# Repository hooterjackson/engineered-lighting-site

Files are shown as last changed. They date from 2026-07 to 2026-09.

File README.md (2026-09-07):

# Engineered Lighting · Engineering Notebook

The prototype series for the Engineered Lighting robotic spotlight — research,
bench builds, perception stack, and software — published as a book-style site.

**Live site:** <https://hooterjackson.github.io/engineered-lighting-site/>
(moving to <https://engineering.engineered.lighting> once DNS cuts over)

## Working on the site

```bash
pip install -r requirements-site.txt
mkdocs serve
```

Every push to `main` builds with `--strict` and deploys to GitHub Pages via
[`.github/workflows/publish.yml`](.github/workflows/publish.yml).

Adding a chapter: drop `09-whatever.md` (numeric prefix, H1 title, optional
`title:` front matter for the sidebar) into `docs/` — the nav picks it up
automatically; no config edits needed. A chapter that belongs in a titled
sidebar group is listed explicitly in `docs/.pages` above its `...` catch-all;
anything unlisted lands after the last group.

Chapter `- [ ]` checklists are interactive on the site (state in the
reader's browser, keyed by page slug + item position) — reordering or
inserting checklist items in a doc shifts readers' saved checkmarks.

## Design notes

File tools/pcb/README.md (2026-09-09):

# PCB chapter generator

This standard-library tool derives Docs 9 and 10 from deliberately cut hardware
snapshots. It never reads routing experiments or edits the source snapshots.
The asset roots `light-v0.1/` and `flex-v0.2/` are stable URL namespaces, **not**
revision claims. JSON, native filenames and download manifests identify revisions.

## Current inputs (8 September 2026)

- Main: `handoff/claude-pcb-learning-cbb8d9fc` in the separate hardware repository.
  LIGHT v0.2, PCB `cbb8d9fc`, 262 features, 241 fitted parts, 71 BOM rows,
  20 schematic sheets.
- Flex: `deliverables/FLEX-mixed-2026-09-08-review` in that repository.
  Upper v0.3 `0af25f8f`; unchanged lower v0.2 `21db9dba` and gimbal v0.2
  `7136c5c3`. There are 292 pads/contacts across the three designs.

Use full hashes from the snapshot verification records, not these short labels.
`build` verifies every MANIFEST.json entry before consuming either snapshot.

## Source contracts

The main handoff contains `viewer-data/board.json`, `bom.json`, `pad-enums.json`
and 17 layer SVGs; `schematic-view/index.json` and sheet SVGs; `downloads/`;
`hardware-current/` native project, BOM, placement and reports;
`fabrication-reference/`; and `public-history/` with portable evidence records.
`engineering-history/` is private input, not a blanket publication source.

The hardware-side `export_viewer_data.py` and `package_handoff.py` in the handoff
are adapted versions of the original exporters. The current packaging adapters
are `scripts/package_learning_refresh.py` and `scripts/finish_learning_snapshots.py`
in the hardware repository. Read them before cutting a later revision; they are
revision-specific, not a promise that arbitrary designs can be substituted.
The current native back-face placement convention differs from the old exporter;
rotation and coordinate checks must remain enabled.

The flex review contains shared verification/electrical/mechanical summaries,
engineering notes and reference templates, plus a directory for each design.
Each directory supplies native project files, connection-table.csv,
design-intent.json, verification.json, ERC/DRC, native geometry, CAM layer SVGs
under view/, and fabrication files. The mixed package was cut with
`scripts/package_flex_learning_refresh.py`, adapting the original
`scripts/check_export_flex.py` workflow. Unchanged designs are copied byte-exact.
The upper native project ZIP includes its custom footprint library.

## Deliberate revision changes

1. Cut and verify the hardware snapshot first. Re-run checks against that exact
   board, or label inherited evidence historical. Never copy old pass counts.
2. Update the main full PCB/ZIP/CSV hashes, SHORT, REVISION and GENERATED in
   build_pcb_assets.py, its revision-specific filenames and teaching entries.
3. Update flex.py DESIGNS if a design directory/version changes. Flex board hashes
   come from verification.json; the directory mapping is still explicit.
4. Update exact revision/census/interface expectations in the tests from the
   independently verified source contract. Do not widen geometric tolerances.
5. Edit chapter prose only outside el-pcb generated marker pairs. Regenerate all
   fourteen blocks; never hand-edit their tables.

## Local loop

Run from this site repository. Set HANDOFF and FLEX to the two snapshot folders
in your own hardware checkout (absolute local paths are not published assets).

```powershell
python tools/pcb/build_pcb_assets.py build --handoff "$HANDOFF" --flex "$FLEX"
python tools/pcb/build_pcb_assets.py render
python tools/pcb/build_pcb_assets.py check
python -m mkdocs build --strict
python -m mkdocs build --strict
.venv/Scripts/python.exe -m pytest tests/e2e -q
```

Use an interpreter with MkDocs for the strict builds, and the site's venv for
pytest. Run `build` twice against frozen inputs and compare every generated byte.
Preview with the `els-site` configuration in `.claude/launch.json`.

## Publication and evidence rules

- Publish only explicit copies in build_pcb_assets.py / flex.py and their download
  manifests: native sources, drawings, derived data, selected evidence, BOM and
  placement files, and deterministic archives. A verified input is not permission
  to publish every file inside it.
- Never publish personal KiCad state, backup directories, fp-info-cache,
  FABRICATION-REVIEW.txt, netlist.xml, vendor identifiers, owner identity or machine
  paths. The scanner checks files and archive members; do not weaken it.
- Never put Markdown under docs/assets. Notes keep their exact bytes as `.txt`.
- `intended`, `cad-checked`, `modelled-current`, `simulated-historical` and
  `measured` describe evidence, not confidence. Neither board has measured data.
  Historical claims link to the byte-exact archived published teaching record,
  containing their bound revision hash; this is not a claim of a new solver run.
- Current full-loop LED electrothermal simulation is not available. The new
  tail/contact resistance screen is narrower. The old A3 upper template is
  explicitly historical; use the current upper 1:1 SVG instead.
- CAM SVGs use a non-native frame. Keep `_frame()` and svgprep's transform
  verification, and the browser copper-bounding-box tests. J100's insertion pads
  belong on B_Cu; all other flex markers retain the F_Cu check. Never relax the
  registration tolerance to accept a visually plausible offset.
- Preserve `docs/assets/pcb/.gitattributes` (`* -text`). After staging, check
  `git ls-files --eol docs/assets/pcb/light-v0.1/kicad/engineered-lighting-rev-a.kicad_pcb`
  reports `attr/-text`, and hash the staged/committed blob, not only the worktree.
- Work on a branch and open a PR against main. CI validates PRs; only a main push
  deploys. Review approval and merging belong to the owner.

The branded successor is cut with `scripts/package_branded_learning.py`. It preserves the original electrical-baseline hashes in evidence, exports current native layer views, and leaves all flex input bytes unchanged.

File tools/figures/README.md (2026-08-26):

# Annotated photo figures — generators

One script per `docs/assets/photo-anno-*.jpg`. Each holds a `COORDS` dict of
pad/pin positions **in original-photo pixels** — the provenance for every ring
and wire the published figure draws — and composes the figure with Pillow.

Inputs are the clean camera originals in `C:\Claude\PrototypeImages`
(IMG_2449 = ESP32-C6, IMG_2450 = Valent X tape, IMG_2452 = PCA9685,
IMG_2456 = ULN2803A); output paths point at the session scratchpad they were
authored in. To regenerate, fix both path sets at the top of the script and
run `python <name>_gen.py` — then copy the render over the published asset.

| Script | Publishes |
|---|---|
| `two-hubs_gen.py` | `photo-anno-two-hubs.jpg` |
| `zone1-chain_gen.py` | `photo-anno-zone1-chain.jpg` |
| `uln-map_gen.py` | `photo-anno-uln-map.jpg` |
| `a0-bridge_gen.py` | `photo-anno-a0-bridge.jpg` |
| `spot-driver_gen.py` | `photo-anno-spot-driver.jpg` (input IMG_2453, rotated 180°) |
| `spot-star_gen.py` | `photo-anno-spot-star.jpg` (input IMG_2507) |

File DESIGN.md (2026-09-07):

# DESIGN — engineering.engineered.lighting

Visual identity for the Engineered Lighting engineering notebook (MkDocs Material).
One idea drives everything: **a dark workshop where exactly the right things are lit.**
The interface is the room; the content is what the light falls on.

Files: `mkdocs.yml` (palette/font/logo config) · `docs/stylesheets/extra.css` (tokens
at the top, everything else consumes them) · `docs/assets/el-logo.svg` + `el-favicon.svg`
· hero markup in `docs/index.md`. No theme fork, no build-chain additions. JavaScript
is confined to `docs/js/` — checklist, lightbox, and Doc 9's PCB viewer — each scoped
to the page that needs it.

---

## 1 · Color tokens

All ratios are WCAG contrast, computed against the surfaces actually used. Everything
interactive or textual meets AA (4.5:1); most of it clears AAA.

### Ground — black ramp

| Token | Hex | Role |
|---|---|---|
| `--el-bg-0` | `#000000` | Page ground, header, drawer |
| `--el-bg-1` | `#0F0D0B` | Raised: admonitions, BoM panels, progress housing |
| `--el-bg-2` | `#17140F` | Highest: kbd, focused search |
| `--el-bg-deep` | `#0B0A08` | Code blocks: a whisper above black |

True black, per the company's darkness-first principle: light is an additive
medium and only exists because of the dark behind it. The warmth lives entirely
in what's *lit* — the ink and the amber — while surface raises keep a faint warm
cast (R > G > B) so panels read as tungsten-touched, never blue-gray slate.
Panels raise by 1–2% lightness with a hairline — no drop-shadows anywhere,
because a shadow implies a light source above the interface, and here light
comes from within.

**Do:** raise a surface with `--el-bg-1` + `--el-line`. **Don't:** `box-shadow`,
blue-tinted grays, or a lifted "app background" — the page itself stays `#000`.

### Ink — warm off-whites

| Token | Hex | Role | On bg-0 |
|---|---|---|---|
| `--el-ink` | `#F2EEE6` | Headings, primary text | 18.1:1 |
| `--el-ink-2` | `#C9C1B2` | Body secondary, nav items | 11.8:1 |
| `--el-ink-3` | `#9C937F` | Captions, table headers, meta | 6.9:1 (6.3 on bg-1) |
| `--el-ink-4` | `#6E6759` | Faint: ¶ marks, footer legal — decorative/large only | 3.8:1 |

Text is 2700 K paper-white, not `#FFFFFF` — full white is reserved for nothing, so
the brightest thing on any page is always an intentional emphasis, never a default.
Hierarchy comes from this ramp plus weight; headings are never colored.

**Do:** dim to de-emphasize. **Don't:** use `--el-ink-4` for any text that must be read
(it's below AA at body sizes — it exists for glyphs and decoration).

### Accent — the tunable-white range, nothing else

| Token | Hex | Role | Contrast |
|---|---|---|---|
| `--el-amber` | `#E2A24C` | Links, active nav, progress, checks (~1800 K) | 9.5:1 bg-0 · 8.9:1 bg-1 |
| `--el-amber-hi` | `#EFBC77` | Hover state | 12.1:1 |
| `--el-amber-soft` | `rgba(226,162,76,.14)` | Tints, checked-box fill | — |
| `--el-ice` | `#D6E5F4` | Emphasis only: focus rings, selection, `mark`, live state (~6500 K) | 16.4:1 |

The site's only two colors are the two ends of the product's tunable-white spectrum.
Amber is *interactive* — if it glows warm, you can act on it. Ice is *attention* —
focus rings, selection, highlights; it never marks a link, so the two channels stay
unambiguous. Charcoal text on an amber button: 8.5:1. No red, no green, no brand blue;
cautionary states (traps) use amber + iconography, informational states use ice.

**Do:** amber = clickable, ice = look-here. **Don't:** amber behind body text, colored
headings, any saturated hue.

### The one light surface

| Token | Hex | Role |
|---|---|---|
| `--el-paper` | `#FFFFFF` | Wiring-diagram sheets |

The wiring SVGs have hardcoded white backgrounds and color-coded wires (+12 V red,
CAN-H orange…) that must not be inverted or hue-rotated — the colors are electrical
semantics. Decision: **keep them white and frame them as lit sheets** — full-bleed
white card, hairline frame, generous padding, a faint halo, mono caption below. A
schematic pinned under a downlight is exactly this brand; a CSS-inverted schematic is
a wiring hazard. (Print drops the framing and runs them full-width.)

## 2 · Typography

One hosted family: **IBM Plex Sans, weights 400 + 600** (the company's brand face;
`font: false` in mkdocs.yml stops Roboto, extra.css imports the two weights). Code and
all "chrome" labels use the **system mono stack** (`ui-monospace, SF Mono, Menlo…`) —
zero extra font weight on a workbench phone connection.

Scale (Material's base: 1rem = 20px; body = 0.8rem = 16px):

| Style | Spec | Use |
|---|---|---|
| Display | clamp(34–47px) / 600 / −0.02em / 1.08 | Landing hero only |
| H1 | 1.7em / 600 / −0.015em / 1.15 | Page titles |
| H2 | 1.3em / 600 / −0.01em | Sections (2.4em space above) |
| H3 | 1.08em / 600 | Sub-sections |
| Body | 16px / 400 / 1.65 line-height | Prose, max-width 42em ≈ 70ch |
| Chrome | mono 10–11px / 0.12em tracking / UPPERCASE | Table headers, admonition titles, captions, meta chips, prev/next labels |

Prose is capped at ~70ch; **tables, code blocks, and diagrams deliberately escape the
measure** and run the full column — BoMs are dense and diagrams want width. The mono
uppercase "chrome" voice is how the product labels itself (telemetry style); on this
site it marks *apparatus* (labels, captions, controls) as distinct from *writing*.
Headings differ by size/weight only — never color.

**Do:** mono-uppercase for labels ≤ a few words. **Don't:** uppercase whole sentences,
a third weight, Title Case.

## 3 · Spacing, radius, borders, motion

- **Spacing:** 4px grid (`--el-sp-*`). Section headings carry 2.4em of air above —
  rhythm comes from space, not rules.
- **Radius:** `0` for every panel, table, code block, button (architectural), `999px`
  only for small floating chips (meta pills, "optional" badges, back-to-top). Nothing
  in between — no 8px "app" corners.
- **Borders:** hairlines `rgba(242,238,230,.10)` and `.20` strong. Depth = border
  + surface step, never shadow. The only glows: the hero source point and the
  faint halo behind diagram sheets.
- **Motion:** 120ms hovers, 220ms fades, `cubic-bezier(.65,0,.35,1)` — damped, no
  bounce, and `prefers-reduced-motion` collapses all of it.

## 4 · The cone-of-light motif

A single radial gradient — `radial-gradient(58% 46% at 50% 0%, warm 15% → transparent)`
— with a 3px source point at its apex. It appears on the **landing hero only** (plus a
"cooling filament" gradient for `hr` dividers). It is never placed behind body text,
never repeated per-section, never animated. One room, one downlight.

## 5 · Component decisions

- **Header:** same color as the page, hairline underline — "no chrome." Search is a
  hairline slot, not a tinted pill.
- **Sidebar:** the repeated site title is hidden on desktop (the header carries it);
  chapter numbers in the existing "3 · Title" form render with tabular numerals; the
  active page is amber @ 600. (Splitting numbers into styled boxes would need template
  or JS changes — see §7.)
- **Admonitions:** quiet panels — hairline border, `--el-bg-1` fill, mono-uppercase
  title, small tinted icon. Informational family = ice; cautionary = amber. Two custom
  types ship in CSS: `!!! trap "…"` (hazard triangle) and `!!! rules "…"`
  (8-point light burst, for the golden rules). No fat left accent bars.
- **BoM checklist:** sections are panels; per-section progress is a mono amber label
  right-aligned in the summary row; the global bar's fill runs **amber → warm white as
  it completes** (the tunable range as a progress metaphor); checkboxes are custom
  15px squares — amber check, ice focus ring, fully keyboard-operable (native inputs,
  visible `:focus-visible`). Buttons are quiet mono-uppercase hairline buttons; the
  one filled (amber) button on the site is the landing CTA.
- **Tables:** hairline horizontal rules only — no zebra, no verticals, no outer box;
  mono-uppercase headers; tabular numerals; a 3%-alpha row hover for tracking dense
  BoM rows.
- **Code:** recessed `--el-bg-deep` + hairline; restrained warm/ice syntax palette
  (strings amber-family, keywords ice-family, comments 5.1:1 — all AA).
- **Footer prev/next:** mono PREVIOUS/NEXT eyebrow + plain title; amber on hover.
- **Print = the light mode:** white ground, warm-black ink, dark-amber links (5.9:1),
  nav/header/hero hidden, diagrams full-width and unframed, page-break guards on
  tables/code/admonitions.

## 6 · Logo

A downlight in section: source point, widening beam, amber pool on the ground —
the product's whole promise in three shapes. `el-logo.svg` (transparent, for the dark
header) and `el-favicon.svg` (on a charcoal tile, bolder geometry for 16px). Both pure
SVG, no text; the wordmark stays typographic.

## 7 · Verified constraints & flagged conflicts

**Verified:** 21 token pairs contrast-checked programmatically — every text/interactive
pair ≥ AA on its real surface (amber on ground 9.5:1; table above; script in review notes). Focus visible
everywhere (2px ice ring, 2px offset). Checklist keyboard-operable. One hosted family,
two weights; no decoration images — gradients only. Mobile: drawer, 44px+ targets on
nav/summary rows, tables scroll within their panels.

**Conflicts with Material's system, and the calls made:**

1. **Light mode:** not shipped. Rationale: print styles already deliver the "paper"
   context; a second screen scheme doubles QA surface and dilutes the identity. The
   tokens are scheme-scoped, so a `paper` scheme can be added later as a second
   `palette:` entry without touching components.
2. **Custom 404** would require a template override (`overrides/404.html`) — that's a
   theme fork by this brief's rules, so it's out of scope; the motif CSS (`.el-hero`)
   is 404-ready if you later allow a one-file override.
3. **Chapter numbers as separate styled elements** in the sidebar can't be done in
   CSS alone (nav labels are plain text); done typographically instead.
4. **`trap`/`rules` callouts** are styled in CSS, but the *content* currently writes
   traps as bold "If stuck:" paragraphs — adopting them means small authoring edits
   (`!!! trap "If stuck — no reply"`). The after-preview of Doc 3 shows one converted
   as a demonstration; no chapter content was otherwise touched.
5. **Scheme base:** built on `scheme: slate` with every visible color overridden,
   rather than a named custom scheme — a custom scheme name drops Material's derived
   defaults and risks unthemed corners (search modal, tooltips). Slate-as-base keeps
   those sane if a Material update adds new surfaces.

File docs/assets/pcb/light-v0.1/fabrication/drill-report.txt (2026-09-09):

Current board cbb8d9fc060c7f2b3e6b27b096a5728e789e816102ddba393c69e91020144abb
868 drill objects: fresh Excellon is identical to the independently compared electrical baseline 80195efd4e08157d8bc64d08c70a84c45f8aff5d4f8d6fb31fbb2f623022d958. Branding changes only back silkscreen. No physical inspection.

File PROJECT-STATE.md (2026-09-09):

# PROJECT-STATE — Engineered Lighting · Robotic Spotlight

*Session-handoff file: the narrative of how this repo got here, and the site's own
build state. It replaces the chat history that produced this repo. Any Claude
(Cowork, Claude Code, claude.ai) on any machine can read it for context; update it
at the end of every working session.*

> ### What to work on next is not in this file — it is in `product-os`
>
> | Question | Authoritative source |
> |---|---|
> | What should I do next, and why? Is it blocked or gated? | **product-os** |
> | Is it actually *done*? (a SHA, a path, a dated note) | **product-os** |
> | How did this project get here, and what does the site say? | **this file** + `docs/` |
>
> Start a session from
> `https://raw.githubusercontent.com/hooterjackson/product-os/main/public/llms.txt`
> — fetchable from any tool, no clone needed. With a clone: `~/Claude/product-os`,
> then `python3 tools/rank.py`.
>
> **Cite the item ID in your first message** (`EL-004`, `SITE-002`). That one token
> is what links the conversation to the work; nothing else recovers it.
>
> This is a pointer, **not a merge** — do not sync the two by hand. When they
> disagree about *status or priority*, product-os wins. When either disagrees with
> a ruling or current bench evidence in `gimbal-bench`, the ruling wins and the
> stale side gets an item.

**Last updated:** 2026-09-07 (Doc 10: the FLEX v0.2 circuits, the pull_request CI trigger, the pinnable board tooltip) — *the last edit to **this file**, not to the repo.
`git log -1` is the repo's real state; this file lags it by design.*

## What this project is

The robotic spotlight for the Engineered Lighting fixture: a silent pan/tilt head
(smart CAN servo actuators, absolute encoders) carrying a high-CRI 3-up LED spot,
exposed to Home Assistant as ordinary entities AND autonomously aimed by a
camera-driven perception stack. Full context lives in the 10-doc series in `docs/`,
published at **https://engineering.engineered.lighting/** (this repo, MkDocs
Material, deployed via GitHub Actions).

## Current state (snapshot)

- **Site:** live — 7 chapters + Doc 3b (frame) + Doc 8 (fixture build, added
  2026-07-29) + **Doc 9 (PCB learning page, 2026-09-07 — implemented and
  validated locally on branch `doc9-understand-the-pcb`; NOT pushed, NOT
  published)** + BoM checklist + AI-workflow page. Adversarial review rounds
  applied throughout, including a sitewide coherence pass after Doc 8 landed
  (seam fixes: Doc 8 body-interface note, Doc 3 + Doc 4 graduation
  pointers → Doc 8, Home card spans Docs 1–4 · 8, totals made derivable
  at $745–1085). Design pass (DESIGN.md) done.
- **Motor swap: DONE sitewide.** Earlier revisions of this file listed two
  prompts as pending; git history shows both were executed before it was
  committed. `8fb39bf` (2026-07-21) propagated RMD-L-4005 → **RMD-L-5005**
  through everything forward-looking (Doc 3 BoM $350–405, end-to-end total
  $640–985, Doc 2's availability addendum keeps the 4005 decision record,
  wiring-SVG labels edited, checklist localStorage IDs preserved). `db41f3f`
  (2026-07-22) added Doc 3b + `docs/cad/frame.scad` (parametric scaffold +
  fit coupon). The prompt files remain in `prompts/` as executed history.
- **Motors purchased; bench is live.** Doc 3 **stage 4 passed 2026-07-31**:
  motor answering on CAN at 0x141, 0xA4 moves commanded and landed to 0.01
  degrees, and the no-homing power-cycle trick verified (the encoder reported
  80.21 deg after a power-off hand rotation). Getting there cost three
  diagnosed failures, all now written into the site: stranded wire fails in
  breadboard clips two ways (splay bare, cold-flow tinned); 12.0 V is this
  24 V-nominal motor's undervoltage-latch line, not a gentle bring-up; and
  when that latches, this unit takes its CAN interface down until a power
  cycle. Doc 4 (LED bench) and Doc 5 (camera) BoMs unordered. Valent X
  sourcing is resolved on the site - click-to-buy at BuyRite/LBC ($486
  spool), BTF FCOB listed as the budget bench substitute.
- **Hardware owned:** RTX 6000 Blackwell GPU box, Home Assistant install,
  Bambu Lab X1C printer (PETG/PETG-CF on hand assumed).

## Pending work queue (in order)

1. **Bench session, in this order** (the order is the safety property):
   flash **v2** and burn down its drill list first (SAFE replays, health
   injection drill) so a regression has one suspect; then flash **v3**;
   then `commission_verify.py` both motors; then **`commission_watchdog.py`
   BEFORE any velocity drill** - 0xB3 is the only protection that survives
   the ESP32 crashing mid-move. Then jog/vel/stop drills, one move through
   the bench-UI path (the first motion came from the USB-CAN adapter), and
   the remaining rituals: multiturn, zero, limits.
2. **Stage 5 characterization** - `tools/sweep_runner.py --live` walks the
   hold/sweep/resolution protocol with dB-meter cues.
3. **Stage 6** - motor B ALONE on the bus, re-addressed to 0x142 via
   `tools/readdress.py` (0x79 is a one-shot persistent flash write).
4. **Frame** - being designed BY HAND on this bench. Doc 3b's generated
   OpenSCAD scaffold stays published as worked reference (constraints,
   STEP-measured motor geometry, boolean test suite), not as a parts list;
   the chapter now says so at the top.
4. **Later, post-bench — fixture integration v0 (hand-soldered):** port the
   Doc 4 architecture off the breadboards onto 2–3 stacked round protoboards
   ("vegetable can" round prototyping PCB, Etsy) inside a fixture body, fed
   from an E26 socket-to-wire adapter → internal 24 V PSU (decision in the
   ledger below; re-verify against the measured worst-case current from
   Doc 3 stage 10 / Doc 4 stage 7 before buying). Build notes banked now:
   reinforce the 24 V and ground rails with solid bus wire (protoboard
   traces don't carry motor current — motor power stays point-to-point in
   18–20 AWG), keep the star-ground topology, PSU on the bottom board away
   from logic, standoffs + a vent path between boards. Component deltas vs
   bench (2026-07-29): same parts, different construction — socket every
   module on female headers (C6 devkit, PCA9685s, SN65HVD230, buck; ULNs
   already socketed), WAGOs → soldered bus + pluggable pigtails (JST-XH
   per tape zone + spot; XT30 for motor power — XH is a 3 A part, RMD
   peaks hit 5–8 A), add 100 nF decoupling at
   each module's supply pins + the bulk cap from the PSU note. ULNs stay
   for v0 (first upgrade candidate if the enclosed soak runs them hot —
   MOSFETs belong to the real PCB per Doc 4). Star heatsink was specced
   for open bench — the enclosed head needs a path to outside air or a
   verified soak. Don't solder until Doc 4 stage 7 passes (freeze the
   validated architecture); first power-up of the stack still happens on
   the current-limited bench supply before the IRM goes in. Wiring docs
   drafted 2026-07-29 (chat deliverables → docs/ + docs/assets/): a
   lane-based system map (wiring-fv0-map.svg), six step diagrams
   (wiring-fv0-step1..6: power → brain → zone 1 → scale → spot → gimbal,
   each with done-when + traps), and chapter 08-build-the-fixture.md —
   all now IN THE REPO (docs/ + docs/assets/): Home + Doc 1 doc-maps
   gained row 8, the series became
   "eight-document", totals propagated $640–985 → $745–1085 sitewide,
   bom-checklist notes Doc 8's BoM lives in-chapter for now, and
   `mkdocs build --strict` verified. Review catches baked in: XT30
   for motor power, 3× 10 kΩ PicoBuck IN pulldowns vs full-on boot
   flash, bulk cap on the motor branch (start 1000 µF), bench-feed break
   in the bus, both-AC-leads-live rule, PCAs live WITH the ULNs on B2.
   The fixture BODY is Marcelo's own design track (his call, 2026-07-29)
   — the docs treat it as a parallel project, not a gap: Doc 8's scope
   note hands that track its interface list (IRM-90-24ST mount +
   terminal-cover room away from LED heat, strain-relieved E26 cord
   entry, 3× M3 standoffs + vent path for the 72 mm stack, tape ring at
   B2 height, full pan/tilt clearance + service-loop slack,
   heatsink→outside-air path, reachable B3 USB-C window). Doc 8's BoM
   folded into the interactive checklist 2026-07-29 (12 new d8-* ids —
   saved state untouched — 31→43 items, e2e count assertions updated;
   bearing drift fixed while in there: 683 or 608 per frame.scad +
   Doc 3b, where Doc 3's BoM had said 6804). Sitewide coherence review done
   2026-07-29; totals recomputed as the straight sum of per-doc highs —
   350–405 + 170–240 + 120–320 + 105–120 = **$745–1085** — and
   propagated (Home hero + footer, Doc 1 reading paths).

## Decisions ledger (one line each — full reasoning is in the docs)

- Actuators: integrated smart CAN servos over DIY FOC (Doc 2). 4005→5005 swap
  is availability-driven; geometry logic: 5005 keeps the slim pancake profile
  (siblings 4010/4015 grow in length, the dimension the yoke cares about).
- Alternates if family sells out again: CubeMars GL40 II (direct-drive, CAN,
  DigiKey) = buy-today fallback w/ protocol port; M5Stack RollerCAN ($44) = dev
  bridge. Full sweep was done July 2026 — Damiao/Robstride/CyberGear ruled out
  (geared/oversized/EOL).
- Beam: fixed Carclo 10507 (~16°); brightness abundant at 330 mA; no zoom
  hardware (beam naturally widens with throw — see Doc 5).
- Control: brightness through HA light entity only; aiming via MQTT
  `spotlight/target` (bench) → ESPHome native-API action (production);
  Auto/Hold/Manual select gates autonomy. Doc 6 is the arbiter when docs
  disagree.
- Software: stack + repo layout + hardware-free testing per Doc 7 (ESPHome
  host-platform simulated fixture is the CI trick). Licensing gates flagged for
  product phase: ESPHome GPLv3, Ultralytics AGPL.
- Spotlight payload (2026-07-29, Marcelo's call): the Cree 3-up star mounts
  in a **DLH-3UP-EH** aluminum LED housing (Ø0.99" finned barrel, 1.26"
  long, hollow 1/2"-14 NPT rear stub = wire exit) — the housing is the
  star's heatsink AND the head's sliding balance mass. frame.scad is at
  **v3** (`b11accb`, 2026-07-29, redesigned after Marcelo's fit review of
  v2): nine flat-printed plates, zero supports, one repeated T-joint
  (printed tabs into slots + M3 bolts into side-loaded square nuts);
  motors BOLTED, never friction-fit (pan = back-cover bolt pattern under
  the base; tilt = face-mount pattern + boss-clearance window, body
  OUTSIDE the arm — the RMD's 4-pin side connector makes any collar
  impossible); 608 sits in a boss-padded full-depth pocket, M8 axle runs
  through it into a captive end-plate nut and installs LAST, so the head
  is supported on both sides and the assembly order is built into the
  geometry; head = boss/main/end plates + face-bolted **cradle_ring**
  (ID = payload_od + 0.6 ≈ 25.75 mm, pinch bolt locks the slide, ring +
  plate grip the barrel near its center); two orthogonal balance trims
  (slide the housing, then the M5 nuts in the tail slot).
  docs/cad/assembly.scad `use`s the real part modules (exploded ↔
  assembled views); Doc 3b rewritten to match ("Nine Flat Parts, One
  Coupon" — the coupon now proves BOTH motor bolt patterns). The planned
  Doc 3b assembly figure was dropped: binary/base64 can't ride the
  text-only GitHub connector (asset corrupted in transit, deleted in
  `ac67684`) — the doc points readers at assembly.scad instead. The
  motor-interface numbers (mount/back BCD 43, bolt Ø2.8, boss clear 34,
  boss len 8) are MEASURE-ME nominals awaiting the calipers step. BoM
  ripple NOT yet applied (Marcelo to call): where the housing purchase
  lands — it supersedes Doc 4's flat heatsink at the fixture stage.
  Doc 3b's BoM delta now carries the small-hardware handful (~$8: M3×10
  + square nuts, M8×35 + nut, M2.5 motor screws).
- Fixture-v0 power (2026-07-29, sized smallest-possible-in-fixture): loads
  split steady vs transient — steady worst case ~25 W as designed (~40 W
  with 2× tape); dual-axis slews add ~30–40 W briefly; balanced hold ≈ 0 W.
  Smallest class: Mean Well **IRM** encapsulated PCB-mount bricks
  (87 × 52 × 29.5 mm, potted, fanless — solders onto the bottom
  protoboard). **IRM-60-24** (2.5 A) is the floor for the as-designed
  build (worst transient ~55–65 W vs its ~69 W hiccup floor — thin but
  real; add 1000–2200 µF low-ESR bulk on the 24 V rail near the motors).
  IRM-45 rejected: dual slews cross its 115% hiccup floor → rail drops
  mid-move. **IRM-90-24** (3.75 A, ~$23) has the IDENTICAL footprint and
  covers 2× tape with margin — same volume, no-regret pick. Fit check
  (2026-07-29): the chosen protoboards are 2.84"/72 mm rounds (Etsy
  "vegetable can" 4-pack, $15, 593 plated holes, no power rails) — the
  87×52 mm IRM outspans them, so use the **IRM-90-24ST** (screw-terminal,
  109×52×33.5 mm) mounted to the fixture body below the stack; that also
  keeps the heaviest part off solder pins near a vibrating gimbal. Plan on
  ~3 of the 4 rounds (power / drivers / logic — connectors eat area fast).
  Fixture-v0 BoM drafted 2026-07-29 (chat deliverable; fold into the
  future Doc 8). Keep the BoM's
  3 A slow-blow on the 24 V side; isolate + strain-relieve the
  line-voltage corner of the stack; no TRIAC/wall dimmer on the E26
  circuit (socket's 660 W rating is a non-issue at ≤100 W input);
  wall-switch power cuts already survivable (absolute encoders, no
  homing). Scaling: +4.6 W (+0.19 A @ 24 V) per foot of Valent X. Confirm
  against the stage-10 measured worst-case current before buying.
  Beginner-review deltas (2026-07-29, round 2): board allocation REVISED —
  B1 power / B2 drivers (PCAs move in WITH the ULNs + zone plugs) /
  B3 logic (C6 + SN65, bottom of stack: USB + antenna + CAN exit) — so
  only ~a dozen wires cross boards instead of all 21 dim signals; stack
  order PSU→B1→B2→B3→gimbal; build flat, stack last, inter-board slack
  1.5×. Chapter gained: Concepts block, five protoboard-soldering rules
  (incl. never-crimp JST + XT30 recessed-live convention), per-step time
  estimates, if-stuck ladders (ULN socket swap-test), a step-7 soak agent
  prompt, and the map gained a physical side-view panel. Wire strippers +
  flush cutters added to BoM maybes.
  Adversarial-review deltas (2026-07-29): 2× tape → DC fuse steps to 4 A
  SB (~3.1 A sustained nuisance-blows a 3 A); bulk cap starts at 1000 µF
  (IRM publishes no max capacitive load — downsize if power-on hiccups);
  spot wiring is 3 independent ± pairs (6 conductors, returns never
  shared); bench-supply limit → ~3 A for full-stack tests; IRM-ST block
  is L/N/+Vo/−Vo only (no FG — Class II, verified against the datasheet);
  Board 1 is over its 72 mm area budget → split power round + a
  driver/connector deck on the third round (wiring identical).

## How to resume on any machine

1. `git clone https://github.com/hooterjackson/engineered-lighting-site.git`
   — or, on an existing clone, **`git fetch` first**. A local tracking ref that
   has not been fetched will answer "up to date" while the remote is dozens of
   commits ahead; it has already lied here by 54.
2. Open the folder in Claude Code (or point a Cowork session at it).
3. Get the queue from product-os, not from this file — fetch
   `.../product-os/main/public/llms.txt` (link at the top) or run
   `python3 tools/rank.py` in `~/Claude/product-os`. Then, first message:
   *"Working on `<ITEM-ID>`. Read PROJECT-STATE.md and the docs it references,
   summarize the state that item depends on, and let's continue."*
4. Note: Cowork **local** sessions stay on the machine they ran on — this file
   carries the narrative and product-os carries the queue and the evidence.
   Neither is chat history. Keep both updated.

### 2026-07-31 — first motor motion; frame authorship; two corrections

**Stage 4 passed.** One RMD-L-5005 on the bench, answering 0x92 and executing
0xA4 to 0.01 deg, power-cycle trick verified. Three failures diagnosed on the
way, all now in the site: stranded motor CAN wires must land in screw
terminals (they fail bare AND tinned in breadboard clips); the motor rail runs
at **24 V** because 12.0 V is this unit's undervoltage-latch line; and a
latched fault takes its CAN interface down until power cycle (power cycle is
the verified recovery, 0x76 untested). LED codes are the fastest instrument:
solid = normal, slow flash = latched Level-2 error.

**Frame: designed by hand from here.** The generated OpenSCAD in Doc 3b stays
published as *worked reference* - the STEP-measured motor geometry, the
2.5 mm tapped depth, the cantilever load argument, the boolean test suite -
but the frame going on this bench is being drawn by hand with that as
inspiration. Doc 3b and Doc 3 stage 7 both say so now.

**Correction to the 2026-07-29 entry above:** it describes the RMD's port as a
"4-pin side connector". It is a **6-pin JST ZH** (VCC, VCC, GND, GND, CANH,
CANL - power doubled up), documented in Doc 3a. The collar-impossible
conclusion still holds; only the pin count was wrong.

**Correction to the frame ledger:** entries describing frame.scad at v3 (nine
flat plates, 608 bearing in a boss-padded pocket) were true as written; the
design has since moved to v8 - four parts, no bearing, no counterweight, the
tilt axis cantilevered off the motor output. See Doc 3b.

### 2026-07-31 (later) — the bench tool becomes a commissioning console

**Direction.** The gimbal debugger is being grown into the tool that sets up
the ESP32 for the whole project: gimbal first, then the LED engine, then
pairing to Home Assistant, then firmware updates. Built after a documentation
sweep (protocol V4.2 read end to end, both vendor manuals, Docs 4/6/7/8, the
Cree and Valent X datasheets) and an adversarial review that changed the
design rather than decorating it - the velocity command was redesigned, a
torque command was cut outright, and several ordering hazards were caught.

**Four decisions, recorded in the Doc 6 addendum where they belong:**

1. The spot star (warm XP-E2 + cool XP-E2 + PC Amber) sits behind ONE
   `light.spot1`, amber folded into the warm end of the CCT dial. No amber
   entity - that would be a second photometric write path.
2. The console is a sanctioned native-API client, but never a second aim
   writer.
3. Motor comm-loss watchdog 0xB3 = 3000 ms, coupled forever to >=1 Hz status
   polling while armed. Change them together or not at all.
4. Persistent motor writes stay in ritualized one-shot tools. Never firmware,
   never a UI button.

**Commissioning values sheet** (what the bench writes into the motors):
CAN ids pan 0x141 / tilt 0x142 · 0xB3 = 3000 ms · multi-turn save ON ·
travel limits mirroring +/-170 and +/-90 (UNIT UNDOCUMENTED - the tool
discovers it by probing) · accel planners in 100..60000 dps/s, and 0 on index
0 means direct tracking, not "no limit" · PID indexes are the non-contiguous
set {01,02,04,05,07,08,09} and float-format writes need motor firmware
>= 20240528.

**Known-unknowns kept as bench experiments:** 0xB6 active-reply semantics ·
whether 0x20-03 fault push persists · whether the motor-side angle limit
gates relative moves at all · what a relative move does to an axis already
running a speed loop (firmware refuses that combination until someone runs it
on purpose).

**Motor firmware updates: there is no field path.** Both manuals were checked.
Recovery and deep configuration go through the vendor's Windows setup software
over the motor's 4-pin serial port, so a USB-TTL adapter belongs in the bench
kit. This is also why `commission_verify.py` exists: a drive that loses its
CAN interface gets recovered by a factory restore that wipes its identity and
tuning, and the JSON snapshot is what makes that survivable.

**Naming:** the artifacts keep their names - the repo is still `gimbal-bench`,
the tool still lives in `tools/bench_ui`. "Commissioning console" is what it
is becoming, not a rename.

### 2026-09-07 — Doc 9: the LIGHT v0.1 PCB, viewable and downloadable

**What landed.** A final chapter, `docs/09-understand-the-pcb.md`, built around an
interactive viewer of the real board: `docs/js/pcb-viewer.js` (board viewer, part
finder, detail panel, parts-list cross-selection, 19-sheet schematic browser, hash
routing, a read-only `window.elPcb` debug API) and `docs/stylesheets/pcb.css`
(section 17, scoped to `.el-pcb` / `.el-sch`). Both registered in `mkdocs.yml`;
that plus two lines in `docs/.pages` are the only config changes.

**The governing hardware** is `engineered-lighting-rev-a.kicad_pcb`, SHA-256
`c046202efa3896d59d12bf19f55ed48b3a6c77532aac199a3a1e9a993e449310`. The page is
generated from the handoff folder prepared on 2026-09-06 and never modifies it.

**Generator.** `tools/pcb/` (standard library only) has three modes: `build
--handoff <folder>` verifies the hash chain and derives every published asset;
`render` regenerates the page's static blocks from the published JSON; `check`
re-verifies hashes, counts, the manifest and the generated blocks **without** the
handoff, so CI and the data tests can run it. Regenerate with:

```
python tools/pcb/build_pcb_assets.py build --handoff "<handoff folder>"
python tools/pcb/build_pcb_assets.py check
```

**Published assets** live under `docs/assets/pcb/light-v0.1/` — about 27 MB: 17
layer plots, 19 schematic sheets, the loose KiCad sources, the complete project
ZIP, the parts CSV, two PDFs, two assembly drawings, the fabrication reference,
and four derived JSON files. Largest single file is the 5.6 MB `.kicad_pcb`; the
previous repo maximum was a 634 kB photograph.

**`docs/assets/pcb/.gitattributes` is load-bearing.** `core.autocrlf=true` plus
CRLF source files would rewrite line endings on commit and break every SHA-256 in
the provenance chain on a Linux CI checkout. `* -text` prevents that; verified
with `git ls-files --eol` and by re-hashing the staged blobs.

**Manufacturing scope stated on the page** (as of 7 September 2026): PCBWay has
been asked to quote five fabricated boards, two of them fully assembled with all
248 purchased parts and three supplied bare. Nothing paid or authorised; assembly
process, stencil and via treatment and factory substitutions not approved. Hand
soldering appears only as optional rework. Older "bare boards for local hand
assembly" wording in the handoff and in the CSV comments is explicitly superseded.

**What the page does not claim.** No board has been powered; no firmware has been
built or flashed. Every component claim carries an evidence class — intended,
cad-checked, modelled-current, or simulated-historical bound to the older board
hash it actually came from. `measured` is never used, and a data test fails the
build if it appears.

**Checks run.** `mkdocs build --strict` twice, clean; the CI add-a-doc rehearsal;
`pytest tests/e2e -q` → **47 passed** (10 pre-existing, 14 new data checks, 23 new
browser checks). Screenshots in `test-artifacts/screens/pcb-*.png`. Layout verified
at 390, 1280 and 1800 px with no page-level horizontal scroll.

**Two fixes worth remembering.** `tests/e2e/conftest.py` now spawns
`sys.executable` rather than a literal `python3`, so the interpreter running the
tests is the one serving the site. And Material's `.md-typeset ul:not([hidden])`
rule outranks a plain class selector, so any list the viewer hides needs either
higher specificity or the `[hidden]` guard now at the top of `pcb.css`.

**Two-interpreter workflow on this machine.** The global Python 3.12 has MkDocs
but a broken pytest; the repo `.venv` has pytest and Playwright but no MkDocs.
Build with the global interpreter, test with `.venv/Scripts/python.exe -m pytest`.

**Open, and needing the owner's call before publication:**

1. The loose `.kicad_pcb` and 19 `.kicad_sch` files are published *in addition to*
   the project ZIP, as the brief asks — about 7 MB of duplication.
2. The fabrication-reference ZIP (Gerbers, drills, IPC-D-356) is derived from the
   same source and scanned clean of quote details, but has not been owner-reviewed.
3. Repository growth of roughly 27 MB.
4. Doc 9 hides its table of contents so the board and its detail panel fit side by
   side at 1280 px, as `bom-checklist.md` already does.

**Deployment.** Approved and performed the same day: branch pushed, pull request
1 merged with a merge commit (`77cdafa`), CI green, and the chapter is live at
https://engineering.engineered.lighting/09-understand-the-pcb/. The hash chain was
re-verified against files fetched back from the published site.

### 2026-09-07 (later) — Doc 10: the FLEX v0.2 circuits, a branch gate, and a board tooltip that stays put

Three separate pieces of work, in the order they were asked for.

**A `pull_request` trigger on the publish workflow.** The pull request for Doc 9
showed no checks at all, because `.github/workflows/publish.yml` only ran on pushes
to `main`. It now also runs on `pull_request` against `main`, so a branch is
validated *before* it lands rather than after. The `deploy` job carries
`if: github.event_name != 'pull_request'`, so a pull request can build and test but
can never publish, and `concurrency` is keyed by `github.ref` so a branch's run does
not cancel `main`'s. The social-card step still fails on CI for want of `cffi`; that
is pre-existing on `main` and unrelated.

**Doc 10 — `docs/10-the-flex-circuits.md`.** Three passive flexible circuits, from
their own KiCad sources, each governed by its own hash:

| Circuit | Design | Copper | Pads | `.kicad_pcb` SHA-256 (first 8) |
|---|---|---|---|---|
| Arm ribbon | `gimbal-static-v0.2` | 1 layer | 70 | `7136c5c3` |
| Upper cylinder band | `led-upper-v0.2` | 2 layers | 120 | `a5acd2a0` |
| Lower cylinder band | `led-lower-v0.2` | 2 layers | 96 | `21db9dba` |

`tools/pcb/flex.py` (invoked as `build_pcb_assets.py --flex`) verifies each hash,
renders 16 layer plots, extracts all 286 pads from the connection tables, publishes
the native sources and builds deterministic fabrication ZIPs. 53 files, 2.5 MB.

The one genuinely hard part was registration. KiCad plots these layers in a CAM
frame, not in board millimetres, so the pad coordinates from the connection table
would have landed somewhere plausible but wrong on top of them. `_frame()` parses
the `translate(A B) scale(1 -1) translate(C D)` wrapper KiCad emits and derives
`displayed_y = native_y − (D − B)`; `svgprep.prepare()` grew `wrap_transform` and
`view_box` parameters to apply it. `test_pads_are_drawn_on_the_copper` checks the
result the only way that means anything: it measures the rendered `F_Cu` bounding
box in the browser and asserts every one of the 286 markers falls inside it, on all
three boards.

One asset needed renaming. The review folder's `ENGINEERING-NOTES.md` is
Markdown, and anything ending `.md` under `docs/` is a chapter as far as MkDocs is
concerned — it was rendered as a page and awesome-pages appended it to the nav
*after* Doc 10. It is published as `ENGINEERING-NOTES.txt` instead; the bytes and
therefore the hash `34a74c6a3252` are unchanged. `test_no_asset_is_paged_by_mkdocs`
guards the whole `docs/assets` tree against a repeat.

`docs/js/flex-viewer.js` reuses the Doc 9 viewer through `window.elPcbKit`, a small
export of `PanZoom` and the DOM helpers. Two things it needed that Doc 9 did not:
these circuits are up to sixteen times longer than they are wide, so fitting the
whole length draws an unreadable hairline — the default view fills the frame with
the circuit's *height* and the reader pans along it, with a "Whole circuit" button
for the overview. And the layer cache originally stored `true` rather than the
markup, so returning to a board you had already visited rendered nothing; it now
caches `innerHTML`.

The page states its numbers honestly: the 0.346 mm worst-case alignment hold against
a 0.30 mm requirement is a computed margin, not a passed physical test, and nothing
has been submitted, ordered or paid for.

**A tooltip you can inspect without being moved.** Clicking a component on the Doc 9
board used to jump the page straight to that part's parts-list row, which on a phone
meant you could never look at a part without losing the board. Hover and click now
both open the same summary; clicking *pins* it, with a close button, and the jump to
the parts list is a button inside the summary. Hovering elsewhere no longer disturbs
a pinned summary, `markBOM` no longer scrolls, and `jumpToRow` does the scrolling and
announces it. Four tests cover the new behaviour, including a touch-only path that
asserts the page does not scroll on tap.

**Sitewide.** `docs/.pages`, `mkdocs.yml`, both document maps, the "ten-document"
phrasing, the `10 documents` hero chip, both reading paths, Doc 9's related reading
and Doc 8's forward-looking section. Doc 10 hides its table of contents for the same
reason Doc 9 does.

**Checks.** `mkdocs build --strict` twice with no warnings; `pytest tests/e2e -q`
green including 12 new flex tests; the asset scanner clean over both asset roots.

### 2026-09-08 - Docs 9/10 refreshed from the central LED revision

**Ground truth before site edits.** The accepted hardware cut, not the autorouting
experiments, supplied main LIGHT v0.2 and upper flex v0.3. All 773 entries in the
hardware FINAL-DIGITAL-ACCEPTANCE manifest rehashed without a mismatch. Accepted
manufacturing packages already existed; the missing piece was the site's handoff
and flex-review contract, not an absence of final board files.

| Board | Published native SHA-256 | Change |
|---|---|---|
| Main LIGHT v0.2 | `9c42ff8df4a3ef58ac7f16b248242f106f784dc73b5744aa6eeb2591ec120096` | New central J2 interface and reviewed routing/assembly corrections |
| Upper flex v0.3 | `0af25f8f72fb999db1bad16a8d59541a02c4eb95f838ada6dd6abadba8fe058d` | Full insertion tail with 30 back-side contacts |
| Lower flex v0.2 | `21db9dba94c6b4fd992e7c361f79d360b84270ea8c3a89099156e5972f7d6379` | Unchanged |
| Static gimbal v0.2 | `7136c5c343da3194c0ada81330edd99336b3078152bb8f1ce47f5da158f2287d` | Unchanged |

**Snapshot contracts.** The hardware repository now has
`handoff/claude-pcb-learning-2026-09-08` (196 manifest entries) and
`deliverables/FLEX-mixed-2026-09-08-review` (192 entries). Adapted versions of the
original viewer exporter, handoff packager and flex checker preserve their folder
shapes. The site verifies every manifest entry before derivation. It remains
read-only against both snapshots. Stable asset URL roots retain their old names;
revision fields and download filenames identify the actual new boards.

**What the chapters teach now.** J2 replaces six radial sockets with one Molex
30-contact interface. Zone order is 4,5,6,1,2,3, each +,+,W,N,C: twenty-four distinct
rails, with no joining of the six fused positives. The upper tail itself is the
plug, gold on the back and support on the front, with a 0.30 +/-0.05 mm total
insertion stack. Its full 42.9 mm outline remains. The main has 264 features,
243 fitted packages, 73 BOM rows and 20 schematic sheets. Four M3 holes, USB,
remaining ports and the branding are retained. Prose covers the In2 signal
exceptions, inherited In3 slot/PWM03 return-reference risk, U5 Schmitt replacement,
910-ohm CTRL pull-downs and C504's final factory installation.

**Evidence boundaries.** Current native/parity/physical-connectivity/CAM receipts
are hash-bound to the accepted revision; the site refresh does not claim to have
rerun those main engineering analyses. The upper snapshot's native ERC/DRC, parity,
endpoint oracle and standalone CAM checks were rerun: 126 pads, 222 copper flashes,
252 tracks and 192 drills. Installed strip connectivity remains conditional on
real strip through-rails. Historical per-part calculations link to the byte-exact
archived teaching record containing their original revision hashes. The current
tail/contact resistance screen is downloadable and deliberately excludes a
full-loop thermal qualification. The 0.346 mm alignment risk against 0.30 mm
remains. The old A3 PDF is explicitly historical because its upper tail is obsolete;
the current upper 1:1 SVG and insertion drawing are supplied instead.

**Publication.** Native sources, 20-sheet schematic/PDF, current placement CSV,
BOM, fabrication reference, complete upper native project and custom footprints
are linked. No generated marker content was hand-edited. No chapter was added or
removed, so sidebar/maps/counts/reading paths require no structural changes.
The lower and gimbal asset directories are byte-identical to main's prior commit.
The quotation status distinguishes submitted requests from payment or production
release; neither these PCBs nor their flex circuits have been made or powered.

**Viewer and maintenance.** The main header now derives its short hash from the
loaded data. The upper viewer opens on the insertion tail with B_Cu visible.
Its registration test checks J100 against back copper and all other markers
against front copper, retaining the original geometric tolerance. New tests cover
the exact paired main/flex pinmap, downloadable historical evidence, the full
prose hash and visible insertion contacts. `tools/pcb/README.md` documents both
contracts, explicit publishing rules, evidence vocabulary and the regeneration loop.

**Corrections to the incoming brief.** The final hardware packages existed outside
the older site-input folders. Flex hashes are self-described, but DESIGNS still
hard-codes directory names and required a v0.3 update. The old main builder checked
three governing hashes, not every input; full snapshot manifest verification is
now explicit. The workflow runs one strict build in the PR test job; its other
strict build is in the deploy job, which is skipped for PRs. Local validation
still runs the requested two strict builds. Work is on a branch for review;
merging and production release remain the owner's decisions.

**Validation.** Two asset builds were byte-identical across 163 generated asset/page files;
`render` and `check` passed for all fourteen blocks. Two strict MkDocs builds had
zero MkDocs warnings. The full suite passed: **68 tests**. The scanner inspected
160 published files and every ZIP member. The configured `els-site` preview and
browser screenshots were reviewed. Source/prose whitespace checks passed; original
CAD/SVG whitespace is deliberately preserved under the byte-exact asset policy.
All 161 staged asset files (including .gitattributes) matched their worktree bytes;
the main board reports `attr/-text` and both changed board blobs hash to the values
above. Every previously published lower/gimbal asset matched its existing Git blob.

## 2026-09-08 — PCB material appearance and reference cleanup

Added a Board materials / Engineering colors appearance control to Doc 9.
Material mode uses black substrate, white actual silkscreen, silver-colored pads,
and family-colored bodies recovered from closed native fabrication contours.
Unresolved contours remain outlines: no invented bounding-box component bodies.
These are illustrative 2D materials, explicitly not component 3D models or an
as-built photograph. Layer inspection and front/back interaction remain available.
Duplicate fabrication reference groups are suppressed at runtime, and assembly
references are off by default; the production silk stays authoritative in the
material view. Native sources, published hashes and all generated assets remain
unchanged. The ESP32 mechanical outline was checked directly against U1 User.Eco2
(18 x 25.5 mm, with a 6 mm antenna section). This annotation is guarded by the
exact current board hash; a changed board does not inherit these coordinates.
The shield and finishes are illustrative. The transparent canvas, black mask and
metallic pad gradients were visually inspected in the local preview.

**Validation.** Generator hash/scanner checks and two strict MkDocs builds pass.
The full browser/data suite passes: **70 tests**, including reference deduplication,
material switching, native module overhang and refusal to reuse that annotation
for a different board hash. No hardware sources or manufacturing files are
changed by this presentation update.

## 2026-09-08 — Grouped arm connectors and branded board snapshot

Doc 9 now consumes the deliberately cut cbb8d9fc learning handoff. Governing main
PCB SHA256: cbb8d9fc060c7f2b3e6b27b096a5728e789e816102ddba393c69e91020144abb.
The current native project, 20 schematic sheets, BOM, placement, layer views,
assembly drawings and fabrication reference agree: 262 features, 241 fitted
parts and 71 BOM rows. J9 is the six-contact spotlight connector beside the
separate J13 tilt harness; J10/J11 are removed and J12 pan remains separate.
Teaching explains the independent LED returns and the external pan service loop.
The back artwork contains the orbit logo, wordmark, website and Kahn quotation.

The black substrate, transparent canvas, white production silk, metallic pads,
colored component bodies and engineering-color alternative are preserved. The
hash guard for the unchanged U1 mechanical depiction is bound to the new board.
This remains an illustrative 2D view, not a photograph or full component model.

Electrical baseline 80195efd retains its original evidence attribution. Current
branding DRC and native/export preservation are separate records. Historical
analogue/thermal results were not relabeled as current. Submission prose states
the latest main package is prepared but not yet submitted, the unchanged gimbal
has a PCBWay inquiry, and upper/lower flex inquiries await a custom-stack route.
No hardware has been powered or production released.

All three flex design asset directories remain byte-exact; only the shared flex
index/provenance link to the new main hash changes. Doc 10 explains the updated
main-to-arm connection without inventing a new flex revision. No chapter was
added or removed, so navigation and document counts retain their existing shape.

Validation: two deterministic asset builds, render/check and two strict MkDocs
builds passed. All 71 tests passed, including material styling, module hash guard,
front/back and flex registration, and the new six-contact pin-map regression.
Front/back screenshots were reviewed; the configured els-site preview is served
locally. Publication scanner and source-byte checks remain enabled. Work stays
on the existing material-view review branch; no deployment or merge performed.

## 2026-09-08 — Completed quotation submissions and authorized publication

Updated both hardware chapters and generated status metadata against the completed
submission receipt. The latest cbb8d9fc main and all three unchanged flex designs
now have PCBWay inquiries. The request is five main boards, two fully assembled
with 241 parts each and three bare, plus two of each flex. Supplier copper,
upper-tail construction and assembly-inspection corrections remain open; quotation
submission does not authorize payment, procurement or production. Earlier JLCPCB
main submissions are not represented as this latest revision.

Native revision hashes, evidence attribution, realistic viewer styling and all
three flex design snapshots are preserved. No chapter or navigation changes.
The owner explicitly requested publication, superseding the earlier PR-only hold.
Validation and deployment results are recorded in the associated pull request.

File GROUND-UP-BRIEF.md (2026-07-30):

# Robotic spotlight frame — ground-up redesign brief

Paste this whole file as the first message of a new session.

---

## What I want

Design the printed frame for a two-axis robotic spotlight **from scratch**, in OpenSCAD. Do not start from the existing files. Read them as evidence of what has already gone wrong, then design fresh.

Work in this order, and don't skip ahead:

1. **Establish the component data.** Sources or nothing — see "Two open unknowns" below.
2. **Adversarial review** of the current design (`docs/cad/` in the repo). The defect log below is the accumulated result of four previous rounds; treat it as a list of rules the new design must not violate.
3. **Design and build** the new files.
4. **Second adversarial pass on your own work** — render every part and the assembly, look at the images, run the interference check, re-measure mass and balance. Screenshot everything and actually inspect it.
5. Deliver files + renders, then push.

Take the time to do 4 properly. Every previous round shipped a new defect because the validation was thinner than the design work.

---

## The machine

A pan/tilt spotlight for a home lighting system. Documented as an engineering notebook at **engineering.engineered.lighting**, repo **`hooterjackson/engineered-lighting-site`**, CAD lives in `docs/cad/`.

- **Two motors**, MyActuator RMD-L-5005 (CAN variant). Pan motor hangs the whole machine from a base plate; tilt motor drives the head.
- **Payload**: a LEDdynamics DLH-3UP-EH aluminium spotlight housing — a Ø25 mm barrel — held in a printed clamp.
- **One 608ZZ bearing** on the idle side of the tilt axis.
- Printed in PETG on a Bambu Lab X1C. Zero supports is a hard requirement.
- Bench-mounted via a C-clamp on a tongue off the base plate.

Current parts: `base_plate`, `yoke` (bridge + two arms, one piece), `cradle` + `cradle_cap` (the clamp), `trunnion` (printed axle), `bearing_carrier`. Plus three test pieces: `tol_coupon`, `fit_coupon`, `bore_gauge`. **You are not obliged to keep this parts breakdown** — if a better architecture exists, argue for it. Consider seriously whether the idle side (trunnion + carrier + bearing + 6 screws) earns its place against a single-arm cantilever on the tilt motor's own output bearing.

---

## Two open unknowns — resolve these FIRST

Everything else downstream depends on them, and both previous rounds of guessing produced designs that could not be built.

### 1. The motor's output face

**Does the whole front face rotate, or only an inner disc? Is there a raised boss, and how far does it stand proud?**

This decides whether a printed plate can land flat on the face or must land on a boss and nothing else. A part that bottoms on the stationary housing clamps the motor solid.

Not published anywhere reachable. Evidence so far: the RMD-L manual's RMD-50 drawing shows **no circle between Ø25 and Ø48** on the output view, and the *same manual* explicitly dimensions bosses on the RMD-90 and RMD-120. Suggestive of a flat face; not proof.

**How to close it:** `https://www.dingsmotionusa.com/s/RMD-L-5005-S.STEP`. STEP is plain ASCII — parse `CYLINDRICAL_SURFACE` radii and their axial positions, and the sorted list of distinct radii answers boss diameter, boss height and connector protrusion in one shot. Every host serving it was blocked from the previous session's sandbox; try again, and if it's still blocked ask me to download it and hand it over.

### 2. Does `assembly.scad` render all six printed parts

On my machine it renders only some of them; on the previous session's it rendered all of them, including with a deliberately mismatched file set. Unresolved. Before designing around it, have me run this in OpenSCAD alongside the three `.scad` files and report **which parts appear and exactly what the console says**:

```scad
include <frame_params.scad>
use <frame.scad>
echo(cad_version);
translate([  0,0,0]) yoke();
translate([120,0,0]) base_plate();
translate([220,0,0]) cradle();
translate([300,0,0]) cradle_cap();
translate([360,0,0]) trunnion();
translate([420,0,0]) bearing_carrier();
```

A `WARNING: Ignoring unknown variable` line names the cause immediately.

---

## Verified component data

Everything below has a source. **Anything not on this list, treat as unknown** and either find a source or make the design tolerate both answers.

### RMD-L-5005 motor
Source: *RMD-L Series Servo Actuator User Manual Rev 1.01*, §2.1 "RMD-50 SERIES" drawing — mirrored at `github.com/tigakub/RMD-L`. Plus `dingsmotionusa.com/rmd-l-collection/l-5005-motor-characteristics`.

| | |
|---|---|
| Output flange | **4 × M3 on Ø25 bolt circle** |
| Rear mount | **4 × M2.5 on a 20 × 20 mm square** (= Ø28.28 at 45°) |
| Body | Ø49, height **23.9 mm**, mass **92 g** |
| Through-bore | **Ø8.1** ("S" variant) or Ø12.7 ("L") — two different STEP files, assume mechanically distinct |
| Torque | 0.13 N·m rated, 0.42 N·m peak, 1360 rpm, 14-bit encoder |
| Load ratings | **Not published.** No bearing-load section exists in the manual. |

Earlier versions of this design used six output holes on Ø30 and an M4 rear on Ø43. Both were invented. That error alone made every part oversized by ~11%.

### DLH-3UP-EH housing
Source: `ledsupply.com/content/pdf/DLH-3UP-EH-Assembly.pdf` Rev A, and the LEDSupply product page.

| | |
|---|---|
| Clamped diameter | Ø0.99" = **25.15 mm, ±0.38 mm** ← the drawing's own two-place-decimal tolerance |
| Overall length | 1.26" = 32 mm |
| Surface | **Not finned** — "4 small channels around the diameter of the sleeve", i.e. grooves cut in |
| Mass | **0.9 oz = 25.5 g** |
| Rear stub | 1/2"-14 NPT external, 1/8"-27 NPS internal, **1/8" (3.175 mm) wire hole** |
| Optic | Ø20 mm Carclo triple TIR, ~6 mm tall, sits inside, no holder needed for the 3-Up |
| Material | 6061-T6 |

**±0.38 mm on the clamped diameter is the single most important number for the clamp.** A 0.76 mm spread. The clamp must never bottom out — the screws set the grip, not a hard stop.

**The sleeve unscrews from the slug.** Clamping the sleeve does not restrain the slug. Not a load path in this frame, but worth a build note.

**Unverified on that drawing:** it carries dimensions `0.89`, `0.80`, `0.70` and states what none of them measure. `0.89" = 22.6 mm` has been assumed to be the sleeve length (the grip length available) — plausible, unconfirmed. The stub length is *not* `1.26 − 0.89`; the 1-Up sheet gives a different difference for the same stub.

### 608ZZ bearing
8 × 22 × 7 mm, standard. Bore and OD are toleranced to about −0.008 mm / −0.009 mm (normal class). ZZ or 2RS both fine, ABEC rating irrelevant at these speeds.

---

## Defect log — every real defect found across four rounds

Each of these shipped or nearly shipped. They are the rules.

**Fits and tolerances**
- A printed shaft drawn at 7.85 mm to enter an 8.00 mm bearing bore. External cylinders print **over** size — it would have come out ~8.0 and never gone in. Nothing in the file compensated for print error at all.
- Holes drilled horizontally treated the same as vertical ones. A horizontal hole bridges and its roof sags; it needs its own fit class.
- A block drawn exactly as wide as the slot it drops into. The block grows and the slot shrinks — 0.4 mm of interference.
- A clamp whose hard stop closed before it touched a minimum-tolerance barrel. It would have gripped air.
- A bearing pocket at nominal + 0.05, i.e. interference on a steel race.

**Geometry that did nothing, or the wrong thing**
- A wire channel cut entirely inside a bore — it removed no material.
- Two "lightening pockets" whose placement expression collapsed: a no-op on one arm, a sealed void inside the other.
- A lead-in chamfer unioned *inside* the full-diameter shaft it was meant to chamfer.
- A wire hole copied by symmetry to a side no wire passes through.
- A cable route with a 6 mm gap in it and a 3.5 mm-deep tunnel no cable could be laid into.
- Yoke arms rendered 8.7 mm clear of the bridge — not connected to the part at all.

**Interference — none of these were visible in a render**
- The clamp cap's ear standing inside the tilt motor's output boss.
- The same ear inside the motor *again* after the boss went away and the whole Ø49 body became the obstruction.
- The pan motor's side connector standing inside the hard-stop post.
- A base-plate gusset through the pan motor's body.
- A cable trough cut through the root of the hard-stop post.

**Assembly and print direction**
- Bolts with no straight driver path to them — a one-piece ring clamp where the part's own body blocked every approach.
- Fasteners trapped behind a subassembly installed earlier.
- A 30 mm blade of a hard stop printed standing up, loaded across its layers, with no buttress. Layer adhesion is the weakest direction a printed part has, and a hard stop is the one feature that gets hit.
- Clamp ears 2.6 mm thick carrying the full clamp load of an M3.
- A 32 mm circular pocket roof printed as a bridge where a hexagon with a vertex up would have been a self-supporting 60° peak.
- A shaft run at its minimum diameter along its whole length when only the last 9 mm was inside the bearing — the rest an unsupported plastic cantilever with the head hanging off it.

**Process**
- A `module` defined inside an `if` block — parser error.
- A patch that silently didn't apply because of whitespace, leaving a part rendering empty.
- STL centre-of-mass read straight out of a file exported in *print* orientation and interpreted as if it were in model coordinates. Wrong by the transform.

---

## Design rules that came out of it

- **Every number lives in one file.** `frame_params.scad` is `include`d by both the geometry and the assembly, so the assembly view cannot disagree with the parts you print.
- **Every fit is derived, never typed.** Three measured constants — vertical hole shrink, bridged hole shrink, external shaft growth — and fit functions built on them: `free_h`, `free_hx`, `tap_h`, `press_h`, `slip_s`, `loc_h`, `slot_fit`. A `tol_coupon` part measures those three on the user's own printer, and it is printed before anything else.
- **Anything that must be round prints as a vertical hole or a first-layer pocket.** Never as a bridge.
- **Every joint is a bolt you can see.** No captive nuts, nothing friction-fit. Printed-to-motor joints use the motor's own threads; printed-to-printed self-taps into pilot holes.
- **Where a part lands on a rotating boss it lands on the boss and nothing else** — if a boss exists at all. Derive the recess from the boss height so it disappears when the height is zero.
- **Assembly order is a property of the geometry, not a hope.** Every step must leave the next step's fasteners reachable by a straight driver.
- **Balance by construction, not ballast.** Offsetting the tilt axis above the payload's axis costs nothing and puts the head's measured centre of mass on the axis. It deleted a trim bolt and a washer stack.
- **Zero supports, no overhang past 60°.**
- Print orientation is declared per part inside the file — `part="yoke"` emits a slice-ready STL.

---

## Validation — do all of this, not some of it

**Render and look.** Headless: `xvfb-run -a openscad -o out.png -D 'part="x"' --imgsize=W,H --projection=p --colorscheme=Tomorrow --autocenter --viewall --camera=0,0,0,rx,ry,rz,0`. Then actually read the image. Several defects above were visible and went unnoticed because renders were generated but not inspected.

**Boolean interference check.** The single highest-value technique found. Emit `intersection() { partA_positioned(); partB_positioned(); }` to an STL and measure its volume. Zero volume or no file at all means clear; anything else is a collision. Run it for the head vs the yoke at tilt 0 and ±90°, head vs both motors, plate vs motor, carrier vs arm. **This caught three collisions that no render showed.** Note that OpenSCAD writes no file at all when the result is empty — that is the success signal.

**Mass properties.** `trimesh` on exported STLs gives volume and centre of mass. Use it to (a) find where the plastic actually is before deciding what to lighten, and (b) solve for the tilt-axis offset that nulls the head's CoM. **Export in model coordinates for this, not print orientation** — the transform will silently corrupt the answer otherwise.

**Watertightness.** Check every exported STL.

**Sanity-echo the derived chain** and read the numbers. Span, sweep vs drop, web thicknesses where two pockets cross, thread engagement depths.

---

## Repo and push protocol

If you are running with direct git access, just commit and push normally.

If the only write path is the GitHub MCP connector (`git push` fails, no credentials; direct API/curl blocked):

- `push_files` is **text only** — never send base64 or binary.
- One commit per call, full file content each time.
- **Read the final local bytes immediately before pushing.** Never reconstruct a file from memory or from an earlier read.
- Verify after every push: `git show origin/main:$f | diff - $f | wc -l` must be `0`.

Either way, the site must build clean: `python3 -m mkdocs build --strict`, and `PLAYWRIGHT_BROWSERS_PATH=/opt/pw-browsers python3 -m pytest tests/e2e -q` (9 tests).

**Current repo state:** `frame_params.scad` and `frame.scad` are v7 on main. `assembly.scad` is still v6 — it works with the v7 pair but lacks a version banner and draws M4-sized screw graphics on an M2.5 circle. There is a newer `frame_params.scad` than main delivered as a file in the previous session, carrying the housing tolerance work described above; ask me for it.

---

## Docs that need updating when the CAD settles

- `docs/03b-print-the-frame.md` — the frame chapter. Currently describes v6 numbers.
- `docs/03-build-the-gimbal.md` — row 11 of the BoM still reads "683 or 608 bearings". There is no 683 in this design; it's one 608ZZ, and it needs its own row with the rows below renumbered.
- `docs/bom-checklist.md` — already has the 608 as its own line.

---

## Deliverables

- `frame_params.scad`, `frame.scad`, `assembly.scad` — or a better file structure if you can justify one.
- STL for every part, watertight, in print orientation.
- Renders: every part individually, the full parts layout, the assembly assembled / exploded / sectioned / at tilt extremes.
- A short written adversarial review of the old design and of your own new one, with the numbers behind each claim.
- Pushed to the repo once verified.

**Tell me plainly when a number is unverified.** The whole reason this is a rebuild is that a design was shipped on invented dimensions. "Not published, here's how the design tolerates either answer" is a good outcome. A confident wrong number is not.

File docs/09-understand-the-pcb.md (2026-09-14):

---
title: 9 · Understand the PCB
description: "The integrated LIGHT v0.2 board, part by part: an interactive viewer of the real eight-layer PCB, all 262 features explained from their own nets, the 20-sheet schematic, the exact parts list and the KiCad sources."
hide:
  - toc
---

# Doc 9 · Understand the PCB — LIGHT v0.2, the Integrated Board

**Engineered Lighting prototype series · September 2026**

[Open the PCB build shopping checklist →](09a-pcb-build-bom.md){ .md-button }

Order the remaining parts for two fixtures: motors, optics, diffuser, mounting supplies and exact cable-side connectors. Check off purchases as you order; selection notes identify the items still needing a fit or specification decision.

Everything the bench proved and [Doc 8](08-build-the-fixture.md) hand-soldered has been drawn as one
circuit board: a 76.2 × 75.1 mm disc with a flat under the antenna, eight copper layers, and parts on
both faces. One ESP32-C6 module, two PWM expanders, 21 ambient channels, three constant-current
spotlight drivers, a CAN transceiver for the motors, and a protected 24 V supply feeding all of it.

This chapter is for understanding that board before it exists in your hands. Turn it over, click any
part and find out what it does *there* — not what a resistor does in general, but what this resistor
does on this net. The schematic, the parts list and the actual KiCad files are all here too.

!!! info "Where this sits after Doc 8"

    [Doc 8](08-build-the-fixture.md) is the *previous* stage: the bench architecture hand-soldered onto
    three round protoboards, with a dev-kit ESP32, PCA9685 breakouts, ULN2803 arrays and a PicoBuck
    driver, fed by an internal 24 V supply. It works, and it is how the design was learned.

    This board is the next stage, and it is not the same machine. The switching is done by 21 discrete
    MOSFETs rather than Darlington arrays; the spotlights get three independent constant-current
    drivers rather than one shared board; the power path gains an electronic breaker, a supervisor and
    a physical ARM interlock. **Doc 8's parts, wiring and ESPHome examples are not this board's
    implementation**, and the bench measurements in Docs [3](03-build-the-gimbal.md) and
    [4](04-full-fixture-bench.md) are not measurements of this PCB.

!!! warning "Status as of 8 September 2026 — designed, not built"

    This page shows the latest **grouped arm connectors and branding** revision, `cbb8d9fc`,
    submitted to PCBWay for quotation and engineering review with **241 fitted parts per assembled board**.
    The request is five fabricated main boards: **two fully assembled on both sides with sourced
    components**, and three supplied bare. Earlier main revisions were also submitted to JLCPCB.
    No payment, procurement or production release is authorized. Supplier stack, stencil, via treatment,
    final capacitor installation and substitutions remain open.

    **No LIGHT v0.2 PCB has been powered.** Current DRC and native/export preservation checks bind the
    branded board to the electrically reviewed `80195efd` baseline. That baseline has ERC, pin-parity,
    connectivity and independent CAM evidence. Those checks are not physical tests or a new simulation.

    [Doc 10](10-the-flex-circuits.md) covers the unchanged three flex circuits. The static gimbal has
    a PCBWay inquiry, as do the upper and lower LED flexes: two of each for two fixture prototypes.
    The quote-form copper and upper-tail support/finish placeholders require engineering correction;
    they do not change the specified construction. Assembly inspection settings also await correction.
    Their geometry and hashes have not been revised for this update.

## Latest changes: arm connectors and branding

The three two-pin spotlight sockets became **one six-pin J9** beside the separate **J13 tilt**
connection. Pins **1/2, 3/4 and 5/6** carry spotlight channels 1, 2 and 3. Their LED-minus wires remain
independent driver returns: sharing a connector does not make them ground. **J12 pan** remains a
separate edge connection because its cable terminates at the pan motor.

Wires link J9 and J13 to the static arm flex. The wire service loop must accommodate pan motion of
180 degrees each way; the static flex itself is not qualified as a repeatedly bending hinge.

The underside now carries the small orbit logo, **engineered lighting**, the website and the Louis
Kahn quotation. This branding changed only back silkscreen. Black substrate, white ink, metallic
pads and the overhanging ESP32 depiction remain illustrative viewer materials, not an as-built photo.

The revision sequence is `9c42ff8d` (central LED interface), `80195efd` (grouped arm connectors), then
`cbb8d9fc` (back-side branding). The upper insertion tail and lower/gimbal boards are unchanged.

??? info "Words this chapter uses — open this if any of them are new"

    | Word | What it means here |
    |---|---|
    | **Schematic** | The drawing of what connects to what. It says nothing about where parts sit. |
    | **Layout** | The drawing of where everything physically goes. This page's viewer shows the layout. |
    | **Reference designator** | A part's address on this design: `U1`, `R101`, `J14`. The letter hints at the kind of part (R resistor, C capacitor, U integrated circuit, Q transistor, D diode, L inductor, F fuse, J connector, S switch, TP test point, H mounting hole), and the number identifies the instance. It is not the part's value, and the prefix alone never explains what a part does. |
    | **Net** | One electrical connection, everything joined to it. `GND` is a net; so is `ZONE1_W`. |
    | **Trace** | The physical copper that implements part of a net. A schematic line is a *connection*, not a scale drawing of a wire — one line can become a trace that crosses three layers. |
    | **Rail** | A net that distributes power: `+3V3`, `+5V`, `V24_BUS`. |
    | **Ground** | The circuit's voltage reference and return path. It is not automatically an earth connection. |
    | **Pin vs GPIO** | A chip's physical pin number and its software name are different things. On this board, module pad 25 is the serial transmit line the firmware calls GPIO16. |
    | **Layer** | One sheet of copper inside the board. This one has eight, with insulating material between them. |
    | **Via** | A small plated hole that carries a net from one layer to another. |
    | **Pad** | Exposed copper a part's pin solders to. A pad belongs to the board, not to the part. |
    | **No-connect** | A pin deliberately left unconnected, marked so the design tools know it is intentional. This board has 29 of them. |
    | **Silkscreen** | Printed ink labels. Ink, not copper, and not a connection. |
    | **Solder mask** | The insulating coating over the copper. Its artwork describes the **openings** where copper is left exposed — so a "mask" view shows holes in the coating, not the coating. |
    | **Fab / assembly outline** | A drawing layer showing component bodies and orientation for assembly. Not electrical. |
    | **Courtyard** | The clearance a part reserves around itself so neighbours can be placed and soldered. Nothing physical. |
    | **BOM** | Bill of materials: the parts list. Distinct from *fabrication outputs* (Gerbers, drill files), which describe the bare board itself. |
    | **Bare PCB vs PCBA** | A bare PCB is the board alone. PCB assembly (PCBA) is that board with the parts fitted and soldered. They are quoted, priced and ordered separately. |
    | **ERC / DRC** | Electrical-rule and design-rule checks: automated checks that the schematic and the layout obey stated rules. They do not run the circuit. |

    One more, because it matters on this page: an animated path showing where current *would* flow is
    an explanation. It is not a live electrical measurement.

## The board { #the-board }

Start with **U1** at the top — the radio module, the part that overhangs the flat edge. Then find
**J1** on the left, where the 24 V supply lands. Hover or tap any part to see what it does; use **Flip
face** to see the underside, where the power section and the big capacitor live. The reference
labels here are the same ones used in the schematic and in the parts list.

<div id="el-pcb" class="el-pcb" data-base="../assets/pcb/light-v0.1/" data-state="nojs" data-face="F" data-preset="components" data-selected="" markdown="0">
<div class="el-pcb-fallback">
<p><strong>The interactive viewer needs JavaScript.</strong> Without it, use the <a href="#assembly-references">assembly drawings</a>, the <a href="#parts-index">parts index</a> and the <a href="#connectors">connector pinmaps</a> below, or the <a href="../assets/pcb/light-v0.1/downloads/schematic.pdf">complete schematic PDF</a>. Every part on this page is explained in the parts index whether or not the viewer runs.</p>

<noscript>Assembly drawing of the front face of the LIGHT v0.2 board, showing component outlines and reference labels</noscript>
</div>
</div>

??? info "What this view shows — and what it does not"

    The default **Components** view is an *assembly-outline* view: real positions, real body outlines
    from the board's own fabrication layer, real land shapes from its pad data, and the actual
    reference labels. It is not a photograph and not a 3D render. The project includes references to KiCad library 3D models, but no assembled model of this board has been produced or verified, and
    none is published here.

    The black ground is the **specified** solder-mask colour of a board that has not been
    manufactured. Layer colours are view colours chosen for contrast — copper is not orange, and the
    inner layers are not green and pink. The **mask** views show the *openings* where copper stays
    exposed, not the coating. **Courtyard** is placement clearance, not a physical feature.

    Some parts overhang the board edge on purpose: the radio module past the flat, the USB connector
    at the bottom and one connector on the right. They are drawn unclipped, because that is where they
    really are. Turning the board over mirrors the whole geometry once about the board's centre line,
    so what you see is the physical back face, not a mirror image of the front.

    **Inspecting a part.** Hovering one opens a short summary. Clicking or tapping it *pins* that
    summary, so it stays put and gains its own buttons: jump to the part's row in the parts list, open
    its schematic sheet, or drop to the full explanation. Nothing moves the page until you press one of
    those buttons — which is what makes this usable on a phone, where there is no hover and where the
    parts list is a long way down. The pinned summary closes with its **×**, with <kbd>Esc</kbd>, or by
    tapping bare board; the selection itself survives all three.

    **Getting around:** drag to pan, scroll or pinch to zoom, double-click to zoom in. The toolbar has
    zoom, fit and flip buttons for anyone not using a mouse. With the viewer focused, the arrow keys
    pan, <kbd>+</kbd> and <kbd>-</kbd> zoom, <kbd>0</kbd> fits the board and <kbd>f</kbd> flips it. The
    search box finds any of the 262 features by reference, name, value, part number or net — that is
    the fastest route on a phone, and the keyboard-friendly one.

    On a phone, one finger scrolls the page as usual and two fingers pan and zoom the board. If you
    would rather drag the board with one finger, press **Lock board for panning**.

## Earlier changes: the central LED interface { #revision-history }

The first published layout was LIGHT v0.1 (`c046202e`). This page now shows LIGHT
v0.2 (`cbb8d9fc`), paired with upper flex v0.3 (`0af25f8f`). Lower flex and the
static arm ribbon remain v0.2: their native board bytes did not change.

Six radial LED sockets have become **one locking Molex 2005280300 at J2**, on the
left side of the front face. J3–J7 have been removed. The upper flex's tail is the
plug itself; no twenty-four-wire solder harness is needed between it and the main
board. Thirty contacts provide twenty-four distinct connections: each zone gets
two positive contacts and its own warm, neutral and cool switched returns.
**Sharing a connector does not join the six fused positive rails.** Zone 7 still
uses J8 on the underside. Motor, spotlight, USB, ARM and expansion interfaces and
the four M3 mounting holes remain.

Routing this interface required local part moves and new signal paths on In2,
which also carries 24 V copper. The reviewed ground references remain, but they
are not uninterrupted sheets. PWM03 crosses a **1.465544 mm** interruption caused
by the inherited PCA_OE routing on In3. The adjacent/reference copper was reviewed;
edge noise and coupling still need measurements on the prototype. An autorouter's
completed connection is not proof of a good high-frequency return path.

The earlier audit corrections are included too: U5 is now **74HCS08PWJ** with
Schmitt inputs, R526–R528 are **910 Ω**, and C504 has a provisional custom land
without paste. Its one-reflow limit requires final factory installation. These
changes explain why old timing or power calculations cannot simply acquire the
new board hash. The source now has 262 features, 241 fitted packages, 71 BOM rows
and 20 schematic sheets, including the shared interface sheet.

Flip to the back to see the white orbit logo, **engineered lighting**, website and quotation.
The black-and-white finish is a fabrication request, not a photo of a built board.

## How the circuit works

Each heading below names the parts involved; select any reference to jump to it on the board. Facts
are tagged so you can tell a design intention from a CAD result from an open question.

### 24 V in, and what guards it

External 24 V arrives at **J1** — pin 1 positive, pin 2 return — and meets **F1**, a 6.3 A backup
fuse. **D500** clamps incoming spikes. **Q500** is a reverse-blocking transistor: connect the supply
backwards and nothing downstream sees it. **U12** is the real protection: an electronic breaker that
limits current, ramps its output up gently, watches for over- and undervoltage and reports what it
sees. Its behaviour is set by the resistors around it, not by software.

The mains supply is a separate unit. Mains never enters this PCB.

### The protected bus, and the branches off it

Past the breaker the rail is `V24_BUS`. **C504**, the 1000 µF can on the back, is the local energy
store that absorbs the motors' current spikes. **U501** clamps transients close to where they arrive,
and **J16** taps the protected bus for a brake that has not been designed yet.

Every branch leaves through its own fuse: **F2** and **F3** for the two motors, **F4**–**F10** for
the seven ambient zones, **F11** for the logic branch. A fuse rating protects the wiring; it is not a
statement about what the copper can carry, and it is not a current limit.

### Making 5 V and 3.3 V

**U10** converts 24 V to 5 V through **L500**; **U11** converts 5 V to 3.3 V through **L501**. Both
are switching converters, which chop their input and let an inductor average the result — far more
efficient than burning off the difference as heat. The 5 V budget is about **0.8 A in total**,
counting the 3.3 V converter's own draw and the CAN transceiver. That is not 0.8 A of spare
accessory power.

### The controller

**U1** is an ESP32-C6 module: chip, flash, crystal and printed antenna, pre-certified as a unit.
**R1** and **C1** hold it in reset while 3.3 V rises; **S1** restarts it and **S2** selects its
download mode; **J15** is the serial console. Its pad numbers are not GPIO numbers — read the map,
do not count pins.

### The 21 ambient channels

Two PWM expanders, **U2** at address 0x40 and **U3** at 0x41, generate the dimming waveforms. Each of
the 21 channels is the same four parts: a 220 Ω gate resistor, a 100 kΩ pull-down, a 2.2 kΩ pull-up
to the switched gate-bias rail, and an AO3422 MOSFET that completes the LED circuit to ground.

Two details decide whether firmware works on the first try. The expander outputs are **open-drain**:
they can only pull down, so releasing an output is what turns a channel *on*, and the optical duty is
the complement of what you write. And the second expander's outputs are **remapped by routing** —
logical channel 18 is its output 13, logical channel 20 is its output 12. Never subtract 16.

<!-- el-pcb:generated channels start -->

<div class="el-pcb-scroll">
<table class="el-pcb-table">
<thead><tr>
<th>Logical channel</th><th>Zone and colour</th><th>Expander output</th><th>Package pin</th><th>Gate resistor</th><th>Switch</th><th>Leaves at</th><th>Fused by</th>
</tr></thead>
<tbody>
<tr><td>1</td><td>Zone 1 warm</td><td>U2 output 0</td><td>6</td><td><span class="el-pcb-ref" data-pcb-ref="R101">R101</span></td><td><span class="el-pcb-ref" data-pcb-ref="Q101">Q101</span></td><td><span class="el-pcb-ref" data-pcb-ref="J2">J2</span> contact 18</td><td><span class="el-pcb-ref" data-pcb-ref="F4">F4</span></td></tr>
<tr><td>2</td><td>Zone 1 neutral</td><td>U2 output 1</td><td>7</td><td><span class="el-pcb-ref" data-pcb-ref="R102">R102</span></td><td><span class="el-pcb-ref" data-pcb-ref="Q102">Q102</span></td><td><span class="el-pcb-ref" data-pcb-ref="J2">J2</span> contact 19</td><td><span class="el-pcb-ref" data-pcb-ref="F4">F4</span></td></tr>
<tr><td>3</td><td>Zone 1 cool</td><td>U2 output 2</td><td>8</td><td><span class="el-pcb-ref" data-pcb-ref="R103">R103</span></td><td><span class="el-pcb-ref" data-pcb-ref="Q103">Q103</span></td><td><span class="el-pcb-ref" data-pcb-ref="J2">J2</span> contact 20</td><td><span class="el-pcb-ref" data-pcb-ref="F4">F4</span></td></tr>
<tr><td>4</td><td>Zone 2 warm</td><td>U2 output 3</td><td>9</td><td><span class="el-pcb-ref" data-pcb-ref="R104">R104</span></td><td><span class="el-pcb-ref" data-pcb-ref="Q104">Q104</span></td><td><span class="el-pcb-ref" data-pcb-ref="J2">J2</span> contact 23</td><td><span class="el-pcb-ref" data-pcb-ref="F5">F5</span></td></tr>
<tr><td>5</td><td>Zone 2 neutral</td><td>U2 output 4</td><td>10</td><td><span class="el-pcb-ref" data-pcb-ref="R105">R105</span></td><td><span class="el-pcb-ref" data-pcb-ref="Q105">Q105</span></td><td><span class="el-pcb-ref" data-pcb-ref="J2">J2</span> contact 24</td><td><span class="el-pcb-ref" data-pcb-ref="F5">F5</span></td></tr>
<tr><td>6</td><td>Zone 2 cool</td><td>U2 output 5</td><td>11</td><td><span class="el-pcb-ref" data-pcb-ref="R106">R106</span></td><td><span class="el-pcb-ref" data-pcb-ref="Q106">Q106</span></td><td><span class="el-pcb-ref" data-pcb-ref="J2">J2</span> contact 25</td><td><span class="el-pcb-ref" data-pcb-ref="F5">F5</span></td></tr>
<tr><td>7</td><td>Zone 3 warm</td><td>U2 output 6</td><td>12</td><td><span class="el-pcb-ref" data-pcb-ref="R107">R107</span></td><td><span class="el-pcb-ref" data-pcb-ref="Q107">Q107</span></td><td><span class="el-pcb-ref" data-pcb-ref="J2">J2</span> contact 28</td><td><span class="el-pcb-ref" data-pcb-ref="F6">F6</span></td></tr>
<tr><td>8</td><td>Zone 3 neutral</td><td>U2 output 7</td><td>13</td><td><span class="el-pcb-ref" data-pcb-ref="R108">R108</span></td><td><span class="el-pcb-ref" data-pcb-ref="Q108">Q108</span></td><td><span class="el-pcb-ref" data-pcb-ref="J2">J2</span> contact 29</td><td><span class="el-pcb-ref" data-pcb-ref="F6">F6</span></td></tr>
<tr><td>9</td><td>Zone 3 cool</td><td>U2 output 8</td><td>15</td><td><span class="el-pcb-ref" data-pcb-ref="R109">R109</span></td><td><span class="el-pcb-ref" data-pcb-ref="Q109">Q109</span></td><td><span class="el-pcb-ref" data-pcb-ref="J2">J2</span> contact 30</td><td><span class="el-pcb-ref" data-pcb-ref="F6">F6</span></td></tr>
<tr><td>10</td><td>Zone 4 warm</td><td>U2 output 9</td><td>16</td><td><span class="el-pcb-ref" data-pcb-ref="R110">R110</span></td><td><span class="el-pcb-ref" data-pcb-ref="Q110">Q110</span></td><td><span class="el-pcb-ref" data-pcb-ref="J2">J2</span> contact 3</td><td><span class="el-pcb-ref" data-pcb-ref="F7">F7</span></td></tr>
<tr><td>11</td><td>Zone 4 neutral</td><td>U2 output 10</td><td>17</td><td><span class="el-pcb-ref" data-pcb-ref="R111">R111</span></td><td><span class="el-pcb-ref" data-pcb-ref="Q111">Q111</span></td><td><span class="el-pcb-ref" data-pcb-ref="J2">J2</span> contact 4</td><td><span class="el-pcb-ref" data-pcb-ref="F7">F7</span></td></tr>
<tr><td>12</td><td>Zone 4 cool</td><td>U2 output 11</td><td>18</td><td><span class="el-pcb-ref" data-pcb-ref="R112">R112</span></td><td><span class="el-pcb-ref" data-pcb-ref="Q112">Q112</span></td><td><span class="el-pcb-ref" data-pcb-ref="J2">J2</span> contact 5</td><td><span class="el-pcb-ref" data-pcb-ref="F7">F7</span></td></tr>
<tr><td>13</td><td>Zone 5 warm</td><td>U2 output 12</td><td>19</td><td><span class="el-pcb-ref" data-pcb-ref="R113">R113</span></td><td><span class="el-pcb-ref" data-pcb-ref="Q113">Q113</span></td><td><span class="el-pcb-ref" data-pcb-ref="J2">J2</span> contact 8</td><td><span class="el-pcb-ref" data-pcb-ref="F8">F8</span></td></tr>
<tr><td>14</td><td>Zone 5 neutral</td><td>U2 output 13</td><td>20</td><td><span class="el-pcb-ref" data-pcb-ref="R114">R114</span></td><td><span class="el-pcb-ref" data-pcb-ref="Q114">Q114</span></td><td><span class="el-pcb-ref" data-pcb-ref="J2">J2</span> contact 9</td><td><span class="el-pcb-ref" data-pcb-ref="F8">F8</span></td></tr>
<tr><td>15</td><td>Zone 5 cool</td><td>U2 output 14</td><td>21</td><td><span class="el-pcb-ref" data-pcb-ref="R115">R115</span></td><td><span class="el-pcb-ref" data-pcb-ref="Q115">Q115</span></td><td><span class="el-pcb-ref" data-pcb-ref="J2">J2</span> contact 10</td><td><span class="el-pcb-ref" data-pcb-ref="F8">F8</span></td></tr>
<tr><td>16</td><td>Zone 6 warm</td><td>U3 output 0</td><td>6</td><td><span class="el-pcb-ref" data-pcb-ref="R116">R116</span></td><td><span class="el-pcb-ref" data-pcb-ref="Q116">Q116</span></td><td><span class="el-pcb-ref" data-pcb-ref="J2">J2</span> contact 13</td><td><span class="el-pcb-ref" data-pcb-ref="F9">F9</span></td></tr>
<tr><td>17</td><td>Zone 6 neutral</td><td>U3 output 1</td><td>7</td><td><span class="el-pcb-ref" data-pcb-ref="R117">R117</span></td><td><span class="el-pcb-ref" data-pcb-ref="Q117">Q117</span></td><td><span class="el-pcb-ref" data-pcb-ref="J2">J2</span> contact 14</td><td><span class="el-pcb-ref" data-pcb-ref="F9">F9</span></td></tr>
<tr><td>18</td><td>Zone 6 cool</td><td>U3 output 13 (remapped)</td><td>20</td><td><span class="el-pcb-ref" data-pcb-ref="R118">R118</span></td><td><span class="el-pcb-ref" data-pcb-ref="Q118">Q118</span></td><td><span class="el-pcb-ref" data-pcb-ref="J2">J2</span> contact 15</td><td><span class="el-pcb-ref" data-pcb-ref="F9">F9</span></td></tr>
<tr><td>19</td><td>Zone 7 warm</td><td>U3 output 3</td><td>9</td><td><span class="el-pcb-ref" data-pcb-ref="R119">R119</span></td><td><span class="el-pcb-ref" data-pcb-ref="Q119">Q119</span></td><td><span class="el-pcb-ref" data-pcb-ref="J8">J8</span> contact 2</td><td><span class="el-pcb-ref" data-pcb-ref="F10">F10</span></td></tr>
<tr><td>20</td><td>Zone 7 neutral</td><td>U3 output 12 (remapped)</td><td>19</td><td><span class="el-pcb-ref" data-pcb-ref="R120">R120</span></td><td><span class="el-pcb-ref" data-pcb-ref="Q120">Q120</span></td><td><span class="el-pcb-ref" data-pcb-ref="J8">J8</span> contact 3</td><td><span class="el-pcb-ref" data-pcb-ref="F10">F10</span></td></tr>
<tr><td>21</td><td>Zone 7 cool</td><td>U3 output 5</td><td>11</td><td><span class="el-pcb-ref" data-pcb-ref="R121">R121</span></td><td><span class="el-pcb-ref" data-pcb-ref="Q121">Q121</span></td><td><span class="el-pcb-ref" data-pcb-ref="J8">J8</span> contact 4</td><td><span class="el-pcb-ref" data-pcb-ref="F10">F10</span></td></tr>
</tbody></table></div>

<!-- el-pcb:generated channels end -->

Warm, neutral and cool in one zone share a positive wire, so their duties are scheduled not to
overlap: `d_warm + d_neutral + d_cool ≤ 1` per zone, in non-overlapping slots.

### The three spotlights

**U14** gates the spotlight supply, and **U7**, **U8** and **U9** each regulate one LED pair to a
nominal **333 mA** — a calculation from a 0.300 Ω sense resistor and the driver's sense window, not a
measurement. Each channel's LED-minus returns through **its own inductor**. It is not ground, and
joining two of them together breaks the regulation.

### ARM, the supervisor, and SAFE

Nothing lights unless three things agree. The firmware raises `LIGHT_ENABLE`; the physical **ARM**
switch on **J17** must be closed; and **U18**, a supply supervisor, must confirm the 3.3 V rail is
genuinely up. **U5** ANDs the first two, **U19** ANDs that with the supervisor, and the result —
`LIGHT_ENABLE_SAFE` — powers the gate-bias switch **U13**, releases the spotlight supply and, inverted
by **U6**, enables the expanders' outputs.

**SAFE gates lighting only.** It does not remove motor power, and it is not a watchdog on the
controller. After a supply fault the firmware must reinitialise and be armed again; no lighting
command may be silently restored.

### CAN and the motors

**U4** turns the controller's logic-level CAN into the differential pair that reaches both motors
through **J12** and **J13**, each with its own fused 24 V feed. **R22** and the open solder jumper
**JP1** are the optional bus terminator — close it only if this board is one of the bus's two ends.
This PCB powers the smart motors and talks to them; it does not implement their internal drive
electronics.

### The USB island

**J14** is USB-C for programming and the serial console, and it needs external 24 V present: USB
powers only a small sensing and isolation island, never the controller. **U17** parks the
controller's data lines on grounded resistors until the supervisor says the 3.3 V rail is qualified,
and only then connects the host.

### Temperature, expansion, and the mechanics

**U20** measures **local PCB temperature** at I²C address 0x48. It is a digital sensor, not a
thermistor, and it is not an overtemperature cutoff. **J18** is seven bare pads — 3.3 V, ground and
five spare GPIOs — with no header fitted and no spare power budget implied. **TP13**–**TP15** are
boot-strap probes, not expansion pins.

Four M3 holes form a **trapezoid**, so the board fits its mounts one way round. "Up" and "down" for
the connectors mean perpendicular to the board's faces, not toward any edge: **J1** mates upward from
the front; the motor, spotlight and seventh-zone sockets mate downward from the back.
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

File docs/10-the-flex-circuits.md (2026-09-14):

---
title: 10 · The Flex Circuits
description: "Three passive flexible circuits that replace the fixture's hand-cut wiring: an arm ribbon and two cylinder bands that solder straight onto the LED strip ends. Routed, digitally checked, quoted — not built."
hide:
  - toc
---

# Doc 10 · The Flex Circuits — Wiring That Is Manufactured, Not Cut

**Engineered Lighting prototype series · September 2026**

[PCB build shopping checklist →](09a-pcb-build-bom.md){ .md-button }

The checklist includes the two user-applied mounting adhesives, mating plugs and wires needed alongside these manufactured flexes.

The main board in [Doc 9](09-understand-the-pcb.md) now consolidates six radial LED sockets into one locking interface. Everything its
connectors reach — six ambient zones around a cylinder, three spotlight pairs, two motors — has so far
been wire, cut and stripped and soldered by hand, one conductor at a time. These three flexible
circuits replace most of that with something a factory makes to a drawing.

The latest main board groups all three spotlight pairs in **J9**, beside **J13 tilt**. Ordinary wires
connect those plugs to the unchanged static arm ribbon; **J12 pan** terminates separately. The wire
loop across the pan joint must accommodate 180 degrees in each direction. This is not a dynamic-flex
qualification. The six spotlight conductors remain separate, including their three LED-minus returns.
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

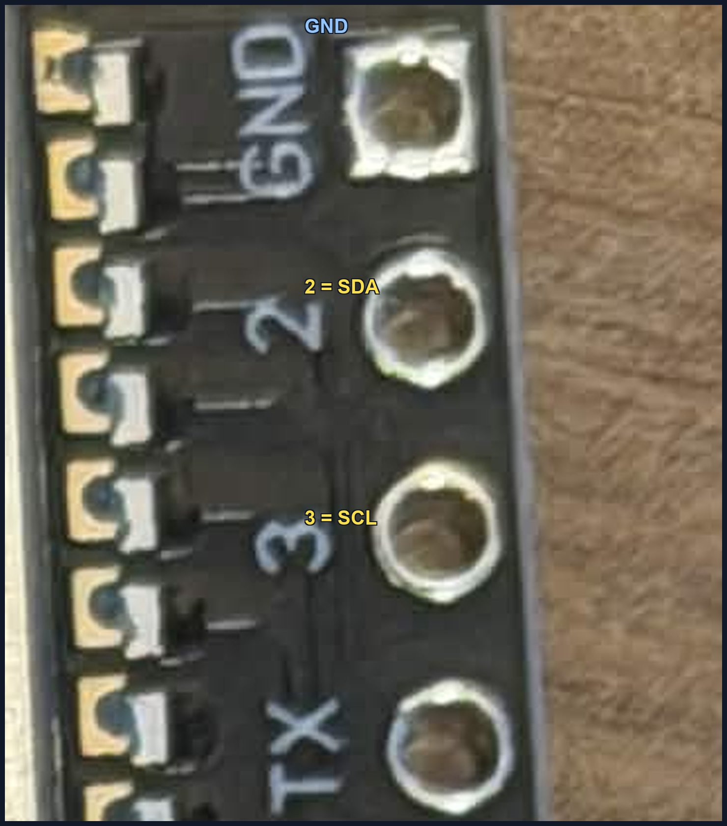
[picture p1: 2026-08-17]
docs/assets/photo-spare-c6-pins.jpg

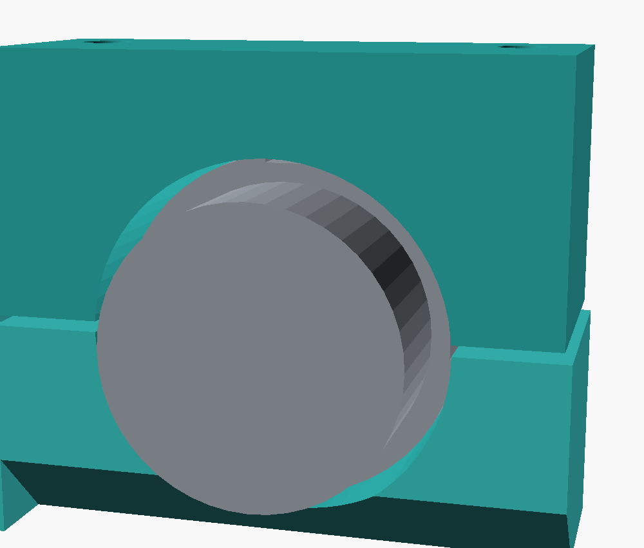
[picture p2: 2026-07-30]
docs/cad/renders/section-head.png

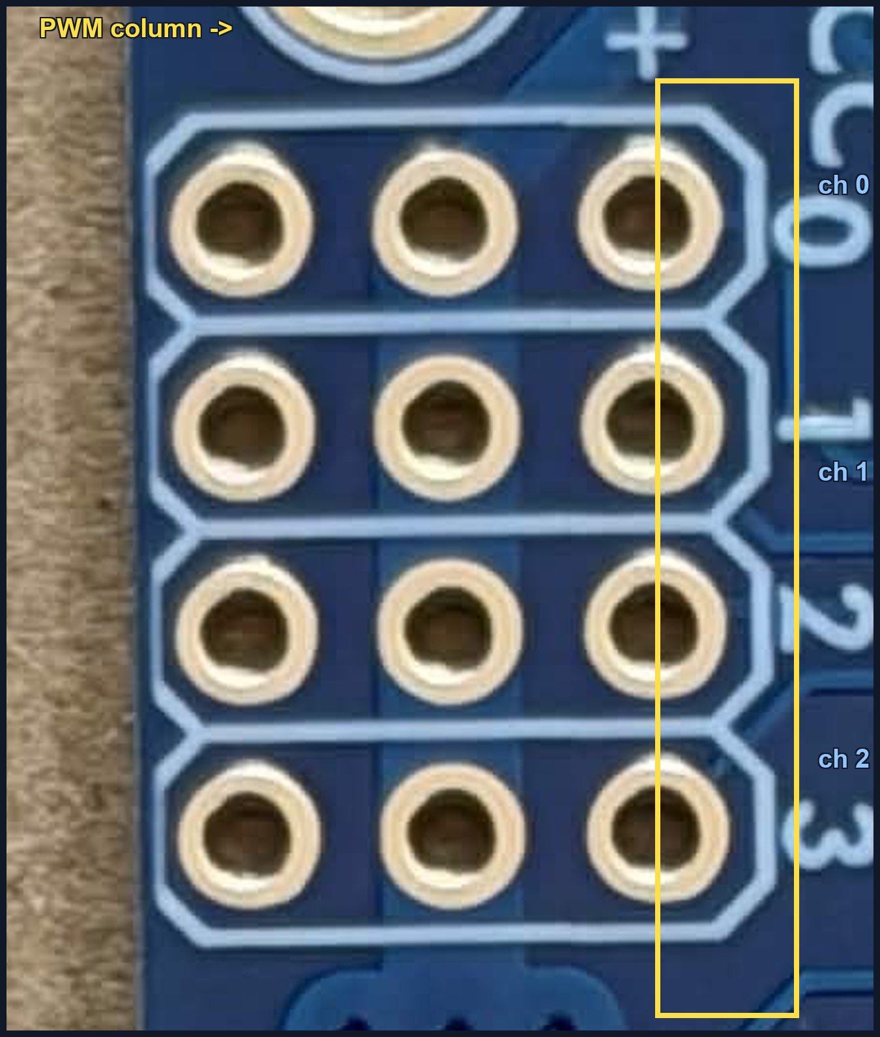
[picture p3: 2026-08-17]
docs/assets/photo-pca9685-channels.jpg

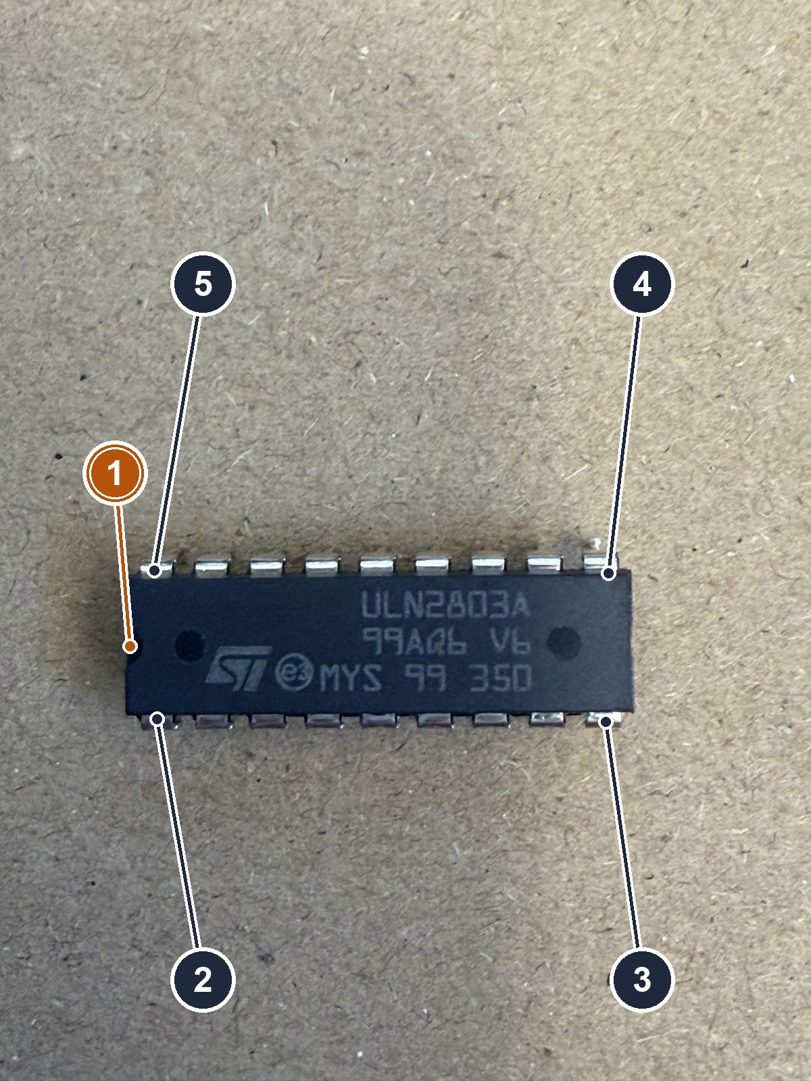
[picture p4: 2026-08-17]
docs/assets/photo-uln2803.jpg

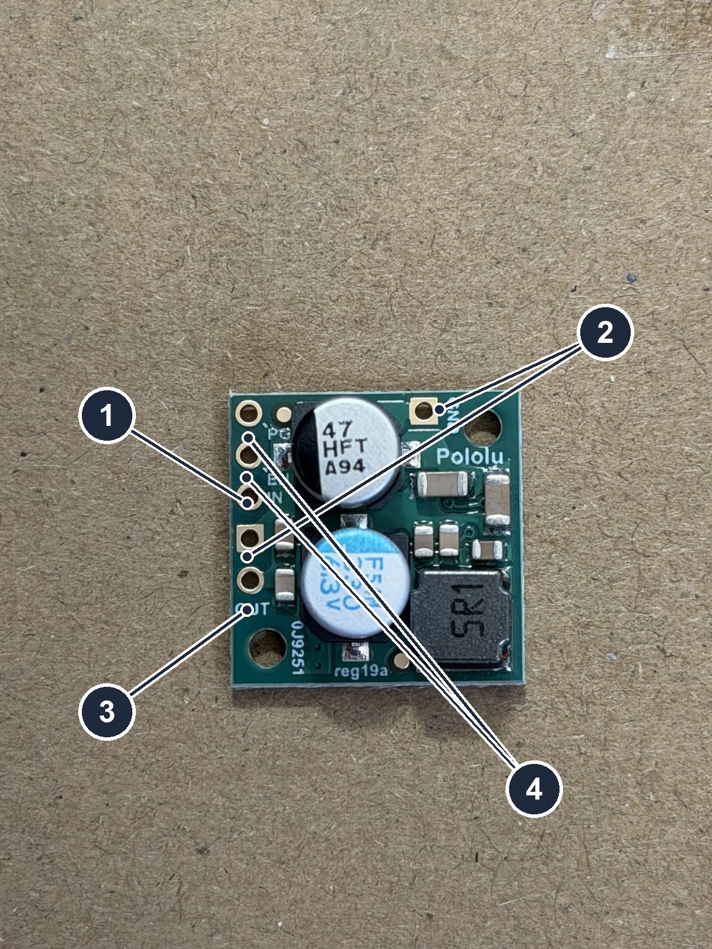
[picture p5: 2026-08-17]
docs/assets/photo-buck-5v.jpg

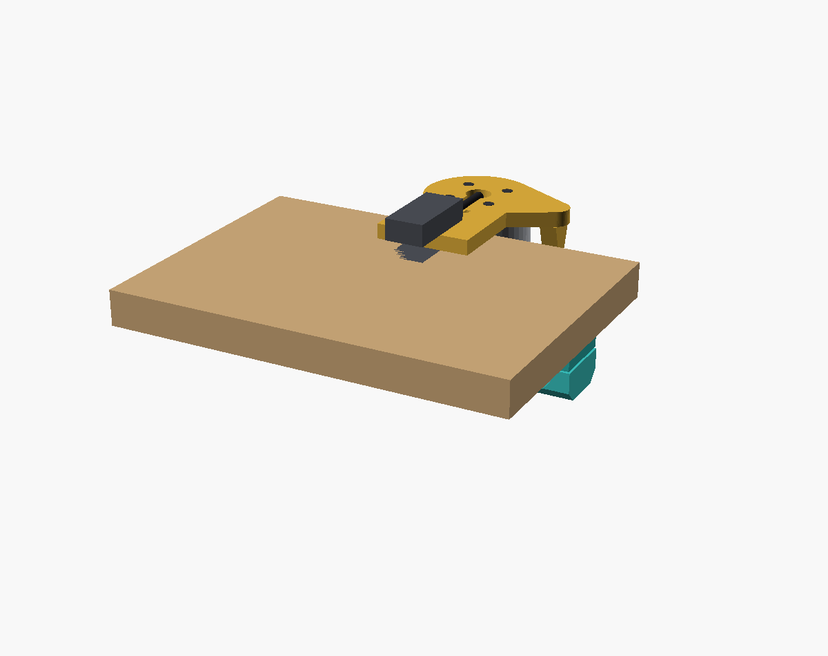
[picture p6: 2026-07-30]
docs/cad/renders/on-the-bench.png

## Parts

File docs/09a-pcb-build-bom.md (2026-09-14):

---
title: 9a · PCB Build Shopping List
description: "Order checklist for two LIGHT v0.2 fixtures: assembled boards, optics, motors, cable-side connectors, wire and mounting supplies."
hide:
  - toc
---

# Buy the parts for the PCB build

**Two complete fixtures · LIGHT v0.2 / cbb8d9fc · reviewed 13 September 2026**

Check a required line when its full quantity for **both fixtures** is covered by an order, usable stock you will have in Canada, or an equivalent included part. If you choose an alternative below, also check the required line it replaces; that line will then leave the remaining-shopping list. Your checks save in this browser, independently of the [earlier bench checklist](bom-checklist.md). They do not sync between your phone and computer.

**Selection notes matter:** “Specified” identifies the required part; it does not certify supplier stock or delivery. Rows saying “Select” or “Confirm” still need that decision before purchase. DigiKey Canada product links were checked on 13 September 2026 where an exact match or clearly labelled candidate was found. Prices, stock and delivery dates can change; verify them in the cart. A Canadian storefront does not mean the parts ship from a Canadian warehouse. Printed gimbal structures and diffuser supports are excluded.

**Order from fewer suppliers:** DigiKey links below cover the cable-side connectors, shorter PA/PH leads, Carclo optic, mounting tapes and selected assembly supplies. Keep the specialist sources for the manufactured PCBs, VALENT X tape, motors, custom spotlight star/housing, diffuser and aluminum tube. PSU/input hardware, moving-wire specification and dimension-dependent fasteners still need selection. Do not add the already-fitted main-PCB components to your order.

<div id="pcb-shopping" markdown="0">
<div class="pcb-order-toolbar">
<div class="pcb-order-meter"><progress id="pcb-order-progress" value="0" max="41" aria-labelledby="pcb-order-total"></progress><strong id="pcb-order-total" aria-live="polite">0 / 41 required purchase lines covered</strong></div>
<p class="pcb-save-message" id="pcb-save-message" role="status">Saved in this browser. Progress does not sync to other devices.</p>
<button type="button" id="pcb-copy-remaining" class="md-button" disabled>Copy remaining required purchases</button>
<textarea id="pcb-copy-fallback" aria-label="Remaining shopping list to copy" readonly hidden></textarea>
<noscript><p>Enable JavaScript to save checkmarks. All products and selection notes remain readable below.</p></noscript>
</div>
<section class="pcb-purchase-section" id="boards">
<h2>Manufactured boards<span class="pcb-section-progress">0 / 4 checked</span></h2>
<table><thead><tr><th scope="col">Product / SKU · mark when ordered</th><th scope="col">For two fixtures</th><th scope="col">Selection</th><th scope="col">Used for / purchase detail</th></tr></thead><tbody>
<tr><td><label class="pcb-product-label" for="pcb-main"><input id="pcb-main" class="pcb-order-box" type="checkbox" data-required="true" aria-label="Covered: LIGHT v0.2 main PCBA · cbb8d9fc" disabled><span data-field="product">LIGHT v0.2 main PCBA · cbb8d9fc</span></label><a class="pcb-product-source" href="../09-understand-the-pcb/">Board and factory BOM</a></td><td data-field="quantity">2 complete assemblies</td><td data-field="selection"><span class="pcb-selection" data-status="reference">Specified</span></td><td data-field="purpose">Both faces assembled; 241 fitted parts per board, including C504 and all board-mounted connectors. A five-board fabrication order leaves three bare spares; those are not additional complete fixtures.</td></tr>
<tr><td><label class="pcb-product-label" for="pcb-upper"><input id="pcb-upper" class="pcb-order-box" type="checkbox" data-required="true" aria-label="Covered: Upper LED flex v0.3 · latest PI-marked files" disabled><span data-field="product">Upper LED flex v0.3 · latest PI-marked files</span></label><a class="pcb-product-source" href="../10-the-flex-circuits/">Flex requirements</a></td><td data-field="quantity">2</td><td data-field="selection"><span class="pcb-selection" data-status="reference">Specified</span></td><td data-field="purpose">One per fixture. Factory reinforcement and connector mating thickness belong in the PCB order. Its tail plugs directly into J2; no separate FFC cable.</td></tr>
<tr><td><label class="pcb-product-label" for="pcb-lower"><input id="pcb-lower" class="pcb-order-box" type="checkbox" data-required="true" aria-label="Covered: Lower LED flex v0.2" disabled><span data-field="product">Lower LED flex v0.2</span></label><a class="pcb-product-source" href="../10-the-flex-circuits/">Flex requirements</a></td><td data-field="quantity">2</td><td data-field="selection"><span class="pcb-selection" data-status="reference">Specified</span></td><td data-field="purpose">One per fixture. Bare passive flex; do not order assembly of LEDs or generic connectors onto it.</td></tr>
<tr><td><label class="pcb-product-label" for="pcb-gimbal"><input id="pcb-gimbal" class="pcb-order-box" type="checkbox" data-required="true" aria-label="Covered: Static gimbal flex v0.2" disabled><span data-field="product">Static gimbal flex v0.2</span></label><a class="pcb-product-source" href="../10-the-flex-circuits/">Flex requirements</a></td><td data-field="quantity">2</td><td data-field="selection"><span class="pcb-selection" data-status="reference">Specified</span></td><td data-field="purpose">One per fixture, with the seven specified back PI supports. User wiring solders to its stations. This is a static flex, not the moving hinge.</td></tr>
</tbody></table>
</section>
<section class="pcb-purchase-section" id="light-body">
<h2>Light, motors and body<span class="pcb-section-progress">0 / 10 checked</span></h2>
<table><thead><tr><th scope="col">Product / SKU · mark when ordered</th><th scope="col">For two fixtures</th><th scope="col">Selection</th><th scope="col">Used for / purchase detail</th></tr></thead><tbody>
<tr><td><label class="pcb-product-label" for="pcb-tube"><input id="pcb-tube" class="pcb-order-box" type="checkbox" data-required="true" aria-label="Covered: Aluminum tube · 4″ OD × 0.065″ wall × 3.5″ long" disabled><span data-field="product">Aluminum tube · 4″ OD × 0.065″ wall × 3.5″ long</span></label><a class="pcb-product-source" href="https://lorenzproducts.com/wp-content/uploads/tube-pipe-straights.pdf">Lorenz · 416AT size catalogue</a><a class="pcb-product-source" href="https://www.metalsupermarkets.com/location/victoria/">Metal Supermarkets Victoria · cut-length quote</a></td><td data-field="quantity">4 cut bodies · 2 fitted + 2 spares</td><td data-field="selection"><span class="pcb-selection" data-status="resolve">Supplier quote / fit check</span></td><td data-field="purpose">Current requested size: actual 4.000″ OD, 0.065″ wall, nominal 3.870″ ID and 3.500″ finished length. Request square, deburred ends and a smooth uncoated exterior. Confirm alloy, tolerances and availability with the supplier. Two extra bodies are prototype spares; this is still a two-fixture BOM. Thermal performance needs the assembled prototype check.</td></tr>
<tr><td><label class="pcb-product-label" for="pcb-tape"><input id="pcb-tape" class="pcb-order-box" type="checkbox" data-required="true" aria-label="Covered: Diode LED DI-24V-VLX-TW1865-016 · VALENT X" disabled><span data-field="product">Diode LED DI-24V-VLX-TW1865-016 · VALENT X</span></label><a class="pcb-product-source" href="https://www.diodeled.com/valent-x-tunable-white.html">Manufacturer</a></td><td data-field="quantity">1 × 16.4′ spool</td><td data-field="selection"><span class="pcb-selection" data-status="resolve">Confirm cut layout</span></td><td data-field="purpose">For two fixtures: 48 × 2.46″ radial segments plus two provisional 9.84″ Zone 7 segments = 11.48′ before waste. One spool leaves about 4.92′. Zone 7 length is not finalized; 9.84″ does not encircle a 4″ OD tube.</td></tr>
<tr><td><label class="pcb-product-label" for="pcb-motors"><input id="pcb-motors" class="pcb-order-box" type="checkbox" data-required="true" aria-label="Covered: MYACTUATOR RMD-L-5005 · CAN variant" disabled><span data-field="product">MYACTUATOR RMD-L-5005 · CAN variant</span></label><a class="pcb-product-source" href="https://www.dingsmotionusa.com/rmd-l-collection/l-5005-motor-characteristics">Motor specifications</a></td><td data-field="quantity">4 motors</td><td data-field="selection"><span class="pcb-selection" data-status="resolve">Confirm order suffix</span></td><td data-field="purpose">Two axes per fixture. Match the exact variant on your existing motors; confirm whether four matching motor cables are included. Subtract usable inventory you will have in Canada.</td></tr>
<tr><td><label class="pcb-product-label" for="pcb-spot"><input id="pcb-spot" class="pcb-order-box" type="checkbox" data-required="true" aria-label="Covered: LEDSupply CUSTOM-3UP-CREE · configured 3-up star" disabled><span data-field="product">LEDSupply CUSTOM-3UP-CREE · configured 3-up star</span></label><a class="pcb-product-source" href="https://www.ledsupply.com/leds/custom-3-up-cree-high-power-led">Configure star</a></td><td data-field="quantity">2</td><td data-field="selection"><span class="pcb-selection" data-status="resolve">Confirm configuration</span></td><td data-field="purpose">Match the bench’s warm-white XP-E2, cool-white XP-E2 and PC Amber. Ask for individually addressable construction with six isolated ± pads and no common connection. Confirm exact CCT/bins and availability; SJX-1 alone is a board marking, not a complete ordering code.</td></tr>
<tr><td><label class="pcb-product-label" for="pcb-housing"><input id="pcb-housing" class="pcb-order-box" type="checkbox" data-required="true" aria-label="Covered: LEDSupply DLH-3UP-EH · 3-up spotlight housing" disabled><span data-field="product">LEDSupply DLH-3UP-EH · 3-up spotlight housing</span></label><a class="pcb-product-source" href="https://www.ledsupply.com/led-heatsinks/3-up-dynamic-led-heatsink-housing">Housing</a></td><td data-field="quantity">2</td><td data-field="selection"><span class="pcb-selection" data-status="resolve">Confirm fit / thermal</span></td><td data-field="purpose">Existing housing identified in Doc 3b, for a 20 mm 3-up star and optic. Manufacturer describes ~3 W passive use and recommends ~350 mA for a 3-up. Confirm clearance and temperatures with the selected emitters and enclosure.</td></tr>
<tr><td><label class="pcb-product-label" for="pcb-optic"><input id="pcb-optic" class="pcb-order-box" type="checkbox" data-required="true" aria-label="Covered: Carclo 10507 · narrow-spot 3-up optic" disabled><span data-field="product">Carclo 10507 · narrow-spot 3-up optic</span></label><a class="pcb-product-source" href="https://www.digikey.ca/en/products/detail/carclo-technical-plastics/10507/2641670">DigiKey Canada · 1066-1054-ND</a><a class="pcb-product-source" href="https://www.carclo-optics.com/products/optic-10507">Carclo fit data</a></td><td data-field="quantity">2</td><td data-field="selection"><span class="pcb-selection" data-status="resolve">Confirm emitter fit</span></td><td data-field="purpose">One primary optic per spotlight; verify with the configured star and housing. 10508 / 10509 are optional beam experiments rather than required extra optics.</td></tr>
<tr><td><label class="pcb-product-label" for="pcb-thermal"><input id="pcb-thermal" class="pcb-order-box" type="checkbox" data-required="true" aria-label="Covered: Spotlight thermal compound" disabled><span data-field="product">Spotlight thermal compound</span></label><a class="pcb-product-source" href="https://www.ledsupply.com/led-heatsinks/3-up-dynamic-led-heatsink-housing">Installation instructions</a></td><td data-field="quantity">1 small package</td><td data-field="selection"><span class="pcb-selection" data-status="resolve">Select SKU</span></td><td data-field="purpose">Thermal interface under each star and on the housing threads as required by the housing instructions. Confirm material compatibility and mounting method; do not count an unrelated bench heatsink as an additional fixture part.</td></tr>
<tr><td><label class="pcb-product-label" for="pcb-diffuser"><input id="pcb-diffuser" class="pcb-order-box" type="checkbox" data-required="true" aria-label="Covered: Yupo Translucent L21-YPT153WH1114 · 153 gsm" disabled><span data-field="product">Yupo Translucent L21-YPT153WH1114 · 153 gsm</span></label><a class="pcb-product-source" href="https://legionpaper.com/yupo-translucent">Manufacturer SKU</a></td><td data-field="quantity">1 × 15-sheet pad</td><td data-field="selection"><span class="pcb-selection" data-status="resolve">Confirm sheet layout</span></td><td data-field="purpose">11″ × 14″ translucent sheets, your preferred stiff diffuser. The current maker SKU uses YPT; the earlier Amazon listing used L21-YUP153WH1114. Confirm diffuser diameter, seam overlap, height and layers before cutting.</td></tr>
<tr><td><label class="pcb-product-label" for="pcb-vhb"><input id="pcb-vhb" class="pcb-order-box" type="checkbox" data-required="true" aria-label="Covered: 3M VHB 4611-0.5-5 · 1.1 mm foam tape" disabled><span data-field="product">3M VHB 4611-0.5-5 · 1.1 mm foam tape</span></label><a class="pcb-product-source" href="https://www.digikey.ca/en/products/detail/3m-tc/4611-0-5-5/7575409">DigiKey · 4611-0.5-5 roll</a><a class="pcb-product-source" href="https://multimedia.3m.com/mws/media/2366513O/3m-vhb-tape-specialty-tape-4611.pdf">3M thickness data</a></td><td data-field="quantity">1 roll · ½″ × 5 yd</td><td data-field="selection"><span class="pcb-selection" data-status="resolve">Trim width to band</span></td><td data-field="purpose">12.7 mm × 4.6 m roll; about 1.30 m is fitted under the four upper/lower flex band bodies. Cut to the 6.4 mm band width and leave solder/access regions clear. Not automatically under the LED strips. Preserve the specified nominal 1.1 mm adhesive stack; verify alignment against the fit drawing.</td></tr>
<tr><td><label class="pcb-product-label" for="pcb-467mp"><input id="pcb-467mp" class="pcb-order-box" type="checkbox" data-required="true" aria-label="Covered: 3M 467MP-0.5-5 · 0.05 mm transfer adhesive" disabled><span data-field="product">3M 467MP-0.5-5 · 0.05 mm transfer adhesive</span></label><a class="pcb-product-source" href="https://www.digikey.ca/en/products/detail/3m-tc/467MP-0-5-5/2649273">DigiKey · 467MP-0.5-5 roll</a><a class="pcb-product-source" href="https://www.3m.com/3M/en_US/p/dc/v000185218/">3M product</a></td><td data-field="quantity">1 roll · ½″ × 5 yd</td><td data-field="selection"><span class="pcb-selection" data-status="resolve">Confirm cut template</span></td><td data-field="purpose">12.7 mm × 4.6 m roll, wide enough to cut the 9.2 mm static gimbal-flex mounting template for two fixtures. User-applied mounting adhesive, not the factory PI-support adhesive. Keep soldering access, joints and cut regions clear according to the mounting template.</td></tr>
</tbody></table>
</section>
<section class="pcb-purchase-section" id="connectors">
<h2>Cable-side plugs and wire<span class="pcb-section-progress">0 / 16 checked</span></h2>
<table><thead><tr><th scope="col">Product / SKU · mark when ordered</th><th scope="col">For two fixtures</th><th scope="col">Selection</th><th scope="col">Used for / purchase detail</th></tr></thead><tbody>
<tr><td><label class="pcb-product-label" for="pcb-pa"><input id="pcb-pa" class="pcb-order-box" type="checkbox" data-required="true" aria-label="Covered: JST PAP-04V-S · PA 4-position housing" disabled><span data-field="product">JST PAP-04V-S · PA 4-position housing</span></label><a class="pcb-product-source" href="https://www.digikey.ca/en/products/detail/jst-sales-america-inc/PAP-04V-S/759976">DigiKey Canada · 455-1488-ND</a></td><td data-field="quantity">4 housings</td><td data-field="selection"><span class="pcb-selection" data-status="reference">Specified</span></td><td data-field="purpose">Main PCB J12 pan and J13 tilt: four housings total. Pin order is power, GND, CAN H, CAN L. PA and PH both have 2 mm pitch but do not mate.</td></tr>
<tr><td><label class="pcb-product-label" for="pcb-pa-leads"><input id="pcb-pa-leads" class="pcb-order-box" type="checkbox" data-required="true" aria-label="Covered: JST APAPA22K51 · 2″ / 50.8 mm, 22 AWG PA lead" disabled><span data-field="product">JST APAPA22K51 · 2″ / 50.8 mm, 22 AWG PA lead</span></label><a class="pcb-product-source" href="https://www.digikey.ca/en/products/detail/jst-sales-america-inc/APAPA22K51/6009460">DigiKey · 2″ APAPA22K51</a><a class="pcb-product-source" href="https://www.digikey.ca/en/products/detail/jst-sales-america-inc/APAPA22K102/9917382">DigiKey · 4″ APAPA22K102</a><a class="pcb-product-source" href="https://www.digikey.ca/en/products/detail/jst-sales-america-inc/APAPA22K152/6009461">DigiKey · 6″ APAPA22K152</a></td><td data-field="quantity">16 pigtails; choose cut plan</td><td data-field="selection"><span class="pcb-selection" data-status="resolve">Confirm short routed length</span></td><td data-field="purpose">Short replacement for the former 12″ lead: same SPHD-001T-P0.5 contacts and stranded 22 AWG wire, compatible with PAP-04V-S. Buy 16 × 2″ leads and remove one terminal from each, or buy 8 × 4″ leads and halve them for roughly 2″ pigtails (8 × 6″ gives roughly 3″). Allow for stripping, termination and movement slack; dry-route before choosing. Contacts are included: omit loose PA contacts. These leads have no verified gimbal torsion-life claim.</td></tr>
<tr><td><label class="pcb-product-label" for="pcb-gh6"><input id="pcb-gh6" class="pcb-order-box" type="checkbox" data-required="true" aria-label="Covered: JST GHR-06V-S · GH 6-position housing" disabled><span data-field="product">JST GHR-06V-S · GH 6-position housing</span></label><a class="pcb-product-source" href="https://www.digikey.ca/en/products/detail/jst-sales-america-inc/GHR-06V-S/807818">DigiKey Canada · 455-1596-ND</a></td><td data-field="quantity">2 housings</td><td data-field="selection"><span class="pcb-selection" data-status="reference">Specified</span></td><td data-field="purpose">J9 spotlight output: 1/2, 3/4 and 5/6 are three independent LED pairs. Do not join the LED-minus wires to ground or to one another.</td></tr>
<tr><td><label class="pcb-product-label" for="pcb-gh4"><input id="pcb-gh4" class="pcb-order-box" type="checkbox" data-required="true" aria-label="Covered: JST GHR-04V-S · GH 4-position housing" disabled><span data-field="product">JST GHR-04V-S · GH 4-position housing</span></label><a class="pcb-product-source" href="https://www.digikey.ca/en/products/detail/jst-sales-america-inc/GHR-04V-S/807816">DigiKey Canada · 455-1594-ND</a></td><td data-field="quantity">2 housings</td><td data-field="selection"><span class="pcb-selection" data-status="reference">Specified</span></td><td data-field="purpose">J8 Zone 7 output: +24 V, W, N, C. No GND contact. The other six zones use the manufactured upper flex.</td></tr>
<tr><td><label class="pcb-product-label" for="pcb-gh-contacts"><input id="pcb-gh-contacts" class="pcb-order-box" type="checkbox" data-required="true" aria-label="Covered: JST SSHL-002T-P0.2 · GH crimp contact" disabled><span data-field="product">JST SSHL-002T-P0.2 · GH crimp contact</span></label><a class="pcb-product-source" href="https://www.digikey.ca/en/products/detail/jst-sales-america-inc/SSHL-002T-P0-2/1642795">DigiKey Canada · 455-1606CT-ND</a><a class="pcb-product-source" href="https://www.digikey.ca/en/products/detail/jst-sales-america-inc/SSHL-002T-P0-2/27687535">DigiKey alternate package ? 100 contacts</a></td><td data-field="quantity">20 fitted + spares; check stock</td><td data-field="selection"><span class="pcb-selection" data-status="resolve">Check stock / package</span></td><td data-field="purpose">12 contacts for spotlight plugs and 8 for Zone 7. Live check on 13 September: the cut-tape page had only one contact available; the 100-contact strip (455-1606-100-ND) showed expected stock on 21 September. Confirm replenishment and package quantity before ordering. Omit loose contacts if a correctly specified harness includes them. Use suitable GH crimp tooling.</td></tr>
<tr><td><label class="pcb-product-label" for="pcb-gh-wire"><input id="pcb-gh-wire" class="pcb-order-box" type="checkbox" data-required="true" aria-label="Covered: 26 AWG stranded wire for JST GH" disabled><span data-field="product">26 AWG stranded wire for JST GH</span></label><a class="pcb-product-source" href="https://www.jst-mfg.com/product/index.php?lang=2&amp;series=105">JST wire limits</a></td><td data-field="quantity">20 conductors; lengths TBD</td><td data-field="selection"><span class="pcb-selection" data-status="resolve">Select compatible SKU</span></td><td data-field="purpose">Must fit GH insulation OD 0.76–1.0 mm and solder to flex/LED pads. Exact product and routing remain open. Do not select thick silicone wire by gauge alone. No GH wire SKU is approved by this list yet.</td></tr>
<tr><td><label class="pcb-product-label" for="pcb-ph"><input id="pcb-ph" class="pcb-order-box" type="checkbox" data-required="true" aria-label="Covered: JST PHR-2 · PH 2-position housing" disabled><span data-field="product">JST PHR-2 · PH 2-position housing</span></label><a class="pcb-product-source" href="https://www.digikey.ca/en/products/detail/jst-sales-america-inc/PHR-2/608607">DigiKey Canada · 455-1165-ND</a></td><td data-field="quantity">2 housings</td><td data-field="selection"><span class="pcb-selection" data-status="reference">Specified</span></td><td data-field="purpose">J17 maintained ARM-switch connection. The board header is vertical, front-face mating.</td></tr>
<tr><td><label class="pcb-product-label" for="pcb-ph-leads"><input id="pcb-ph-leads" class="pcb-order-box" type="checkbox" data-required="true" aria-label="Covered: JST ASPHSPH24K152 · 6″ / 152.4 mm, 24 AWG PH lead" disabled><span data-field="product">JST ASPHSPH24K152 · 6″ / 152.4 mm, 24 AWG PH lead</span></label><a class="pcb-product-source" href="https://www.digikey.ca/en/products/detail/jst-sales-america-inc/ASPHSPH24K152/6009458">DigiKey · 6″ ASPHSPH24K152</a><a class="pcb-product-source" href="https://www.digikey.ca/en/products/detail/jst-sales-america-inc/ASPHSPH24K51/6009457">DigiKey · 2″ ASPHSPH24K51</a><a class="pcb-product-source" href="https://www.digikey.ca/en/products/detail/jst-sales-america-inc/ASPHSPH24K102/9918854">DigiKey · 4″ ASPHSPH24K102</a></td><td data-field="quantity">4 pigtails; choose cut plan</td><td data-field="selection"><span class="pcb-selection" data-status="resolve">Confirm routed length</span></td><td data-field="purpose">Two wires per ARM switch. Two double-ended 6″ leads yield four roughly 3″ pigtails when halved; otherwise use four leads trimmed from one end. Shorter 2″ and 4″ versions are linked. Choose after routing and allow termination length. Contacts are included; omit the loose PH-contact alternative.</td></tr>
<tr><td><label class="pcb-product-label" for="pcb-arm"><input id="pcb-arm" class="pcb-order-box" type="checkbox" data-required="true" aria-label="Covered: Maintained SPST ON–OFF switch · gold logic contacts" disabled><span data-field="product">Maintained SPST ON–OFF switch · gold logic contacts</span></label><a class="pcb-product-source" href="https://www.digikey.ca/en/products/detail/nkk-switches/MN11SS1G01/25693872">DigiKey · MN11SS1G01 candidate</a><a class="pcb-product-source" href="https://www.nkkswitches.com/pdf/MN_ToggleSections_DP.pdf">NKK drawing</a></td><td data-field="quantity">2 switches</td><td data-field="selection"><span class="pcb-selection" data-status="resolve">Select mounting / SKU</span></td><td data-field="purpose">For the low-current 3.3 V ARM input (~0.33 mA), not a mains switch or motor emergency stop. NKK MN11SS1G01 is the gold-contact SPST ON–OFF candidate: 6.5 mm panel opening, 1/4-40 bushing, solder lugs. Confirm mounting clearance before buying; the listing shows supplier stock rather than DigiKey shelf stock.</td></tr>
<tr><td><label class="pcb-product-label" for="pcb-motor-cables"><input id="pcb-motor-cables" class="pcb-order-box" type="checkbox" data-required="true" aria-label="Covered: MYACTUATOR matching CAN motor cable assembly" disabled><span data-field="product">MYACTUATOR matching CAN motor cable assembly</span></label><a class="pcb-product-source" href="https://www.dingsmotionusa.com/rmd-l-collection/l-5005-motor-characteristics">Motor reference</a></td><td data-field="quantity">4 cables</td><td data-field="selection"><span class="pcb-selection" data-status="resolve">Confirm included / pinout</span></td><td data-field="purpose">One per motor; avoid duplicating included cables. Verify the actual six-contact motor pinout and retain both power and both GND contacts. DIY ZH parts are alternatives below, not additional required purchases.</td></tr>
<tr><td><label class="pcb-product-label" for="pcb-psu-wire"><input id="pcb-psu-wire" class="pcb-order-box" type="checkbox" data-required="true" aria-label="Covered: Alpha Wire 3053 · stranded 20 AWG, red and black" disabled><span data-field="product">Alpha Wire 3053 · stranded 20 AWG, red and black</span></label><a class="pcb-product-source" href="https://www.digikey.ca/en/products/detail/alpha-wire/3053-RD005/204392">DigiKey · 3053 RD005 red, 100 ft</a><a class="pcb-product-source" href="https://www.digikey.ca/en/products/detail/alpha-wire/3053-BK005/204390">DigiKey · 3053 BK005 black, 100 ft</a></td><td data-field="quantity">2 pairs; length TBD</td><td data-field="selection"><span class="pcb-selection" data-status="resolve">Select cut length / put-up</span></td><td data-field="purpose">Fixed PSU-to-J1 feed candidate. These exact DigiKey listings are 100 ft spools, far more than two fixtures need; use suitable existing stock or request short cuts instead of buying both by default. J1 takes stripped wire directly, 6 mm strip. No mating plug. Do not substitute solid-wire 3053/1 for stranded 3053.</td></tr>
<tr><td><label class="pcb-product-label" for="pcb-moving-wire"><input id="pcb-moving-wire" class="pcb-order-box" type="checkbox" data-required="true" aria-label="Covered: Flexible service-loop wire or custom moving harness" disabled><span data-field="product">Flexible service-loop wire or custom moving harness</span></label><a class="pcb-product-source" href="../09-understand-the-pcb/#connectors">Board connections</a></td><td data-field="quantity">2 routed harness sets</td><td data-field="selection"><span class="pcb-selection" data-status="resolve">Select after routing</span></td><td data-field="purpose">Movement across pan and tilt needs slack, strain relief and suitable wire construction. The static arm flex stays fixed. This replaces the moving portions of the wire plan above; it is not a second complete set of wires. No generic hookup-wire life claim is assumed.</td></tr>
<tr><td><label class="pcb-product-label" for="pcb-heatshrink"><input id="pcb-heatshrink" class="pcb-order-box" type="checkbox" data-required="true" aria-label="Covered: Panduit HSTT-YK1 · heat-shrink assortment" disabled><span data-field="product">Panduit HSTT-YK1 · heat-shrink assortment</span></label><a class="pcb-product-source" href="https://www.digikey.ca/en/products/detail/panduit-corp/HSTT-YK1/317576">DigiKey Canada · HSTT-YK1</a></td><td data-field="quantity">1 kit, if not already owned</td><td data-field="selection"><span class="pcb-selection" data-status="resolve">Choose diameter per joint</span></td><td data-field="purpose">14 black 2:1 pieces, each 6″ long, in seven diameters from 1/16″ to 1/2″. Cut short sleeves for switch lugs and wire transitions; choose supplied/recovered diameter to fit each actual joint. Keep splices outside moving loops and check the rating for its location. This does not select mains splices.</td></tr>
<tr><td><label class="pcb-product-label" for="pcb-labels"><input id="pcb-labels" class="pcb-order-box" type="checkbox" data-required="true" aria-label="Covered: Wire labels / numbered cable markers" disabled><span data-field="product">Wire labels / numbered cable markers</span></label></td><td data-field="quantity">1 small assortment</td><td data-field="selection"><span class="pcb-selection" data-status="resolve">Select SKU</span></td><td data-field="purpose">Identify both ends, especially all-black pre-crimp leads and the six independent spotlight conductors.</td></tr>
<tr><td><label class="pcb-product-label" for="pcb-strain"><input id="pcb-strain" class="pcb-order-box" type="checkbox" data-required="true" aria-label="Covered: Cable anchors / strain-relief clamps" disabled><span data-field="product">Cable anchors / strain-relief clamps</span></label></td><td data-field="quantity">Enough for 2 fixtures</td><td data-field="selection"><span class="pcb-selection" data-status="reference">Size to cable paths</span></td><td data-field="purpose">Anchor before PCB connectors and flex solder pads; do not let joints take the pull or repeated bend.</td></tr>
<tr><td><label class="pcb-product-label" for="pcb-grommets"><input id="pcb-grommets" class="pcb-order-box" type="checkbox" data-required="true" aria-label="Covered: Edge bushings / grommets / protective sleeving" disabled><span data-field="product">Edge bushings / grommets / protective sleeving</span></label></td><td data-field="quantity">Per final hole schedule</td><td data-field="selection"><span class="pcb-selection" data-status="resolve">Select sizes</span></td><td data-field="purpose">Protect conductors where they cross aluminum edges or holes. Size to actual openings and cable bundles.</td></tr>
</tbody></table>
</section>
<section class="pcb-purchase-section" id="power-fasteners">
<h2>Power input and nonprinted mounting parts<span class="pcb-section-progress">0 / 11 checked</span></h2>
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

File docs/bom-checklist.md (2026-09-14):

---
title: Buy the Parts
description: "Every purchase in the series in one interactive checklist — check items off as you order; progress persists in your browser."
hide:
  - toc
---

# Bill of Materials — interactive checklist

This checklist covers the earlier bench, perception and hand-wired fixture stages. Check items off as you order — state persists in your browser (nothing leaves your device). The full "Notes / traps" for each part live in the chapter BoM tables: [Doc 3](03-build-the-gimbal.md), [Doc 4](04-full-fixture-bench.md), [Doc 5](05-teach-it-to-aim.md), [Doc 8](08-build-the-fixture.md).

**Building the latest LIGHT v0.2 PCB prototype?** Use the [PCB build shopping checklist](09a-pcb-build-bom.md) for two fixtures. Its saved progress is separate: the PCB replaces many modules and wiring parts below. The factory-fitted component BOM remains in [Doc 9](09-understand-the-pcb.md).

!!! note "Prices verified July 2026"
    All prices in the series were verified in July 2026 — **re-check live prices when ordering**. This is the docs' own pre-purchase-recheck rule (see [Doc 7's risk register](07-building-the-software.md)).

!!! tip "Two distinctions that cost more wrong orders than anything else on this page"
    **Solid and stranded wire are not interchangeable, and the listing photos look identical.** Breadboard contacts and soldered bus rails want **solid** core — stranded frays, buckles and reads intermittent in a breadboard, and won't hold its shape as a rail. Anything that flexes or gets handled wants **stranded** — the 24 V runs, the service loops across the pan/tilt joints. "Marine" and "silicone" wire is always stranded, and deliberately floppy.

    **On fuses the letters carry the meaning, not the millimetres.** In 5×20 mm, **GMC is slow-blow and GMA is fast**; in 6.3×32 mm, **MDL is slow and AGC is fast**. Same glass, same size, opposite behaviour. Automotive blade fuses (ATM/ATO/APM) are fast-acting and assortments rarely stock a 3 A at all. Every fuse in this series is a **time-delay** part, because motor inrush plus the bulk cap will nuisance-blow a fast one on power-up.

<div id="bom-global">
  <progress id="bom-bar" max="44" value="0" aria-labelledby="bom-global-text"></progress>
  <span id="bom-global-text">0/44 items</span>
</div>

<details open class="bom-section" data-section="d3" markdown="0">
<summary><strong><a href="../03-build-the-gimbal/">Doc 3 · Gimbal (~$350–405)</a></strong> <span class="bom-progress"></span></summary>
<div class="bom-scroll">
<table>
<thead><tr><th></th><th>Part</th><th>Qty</th><th>Est.</th><th>Where</th><th>Why</th></tr></thead>
<tbody>
<tr><td><input type="checkbox" class="bom-box" id="d3-motors" data-lo="215" data-hi="322.5" aria-label='MyActuator RMD-L-5005-100-C (CAN variant)'></td><td><label for="d3-motors">MyActuator RMD-L-5005-100-C (CAN variant)</label></td><td>2 (+1 spare rec.)</td><td>$215 / $322.50 for 3</td><td><a href="https://www.dingsmotionusa.com/rmd-l-5005">Dings Motion USA</a>, $107.50 ea</td><td>The smart pan/tilt actuators — order the <strong>-C (CAN)</strong> variant, and ask for mating cables for the <strong>6-pin JST ZH</strong> port — ZH, not the larger XH (<a href="../03a-wire-the-bench/">Doc 3a</a>); third unit = permanent bench spare</td></tr>
<tr><td><input type="checkbox" class="bom-box" id="d3-esp32" data-lo="9" data-hi="15" aria-label='ESP32-C6 dev board (ESP32-C6-DevKitC-1)'></td><td><label for="d3-esp32">ESP32-C6 dev board (ESP32-C6-DevKitC-1)</label></td><td>1</td><td>$9–15</td><td>Amazon, Adafruit, DigiKey</td><td>Same chip as the fixture — everything learned transfers</td></tr>
<tr><td><input type="checkbox" class="bom-box" id="d3-can-xcvr" data-lo="8" data-hi="8" aria-label='SN65HVD230 CAN transceiver breakout (Waveshare "CAN Board")'></td><td><label for="d3-can-xcvr">SN65HVD230 CAN transceiver breakout (Waveshare "CAN Board")</label></td><td>2 (1+spare)</td><td>$8</td><td>Amazon</td><td>The CAN line driver — turns chip signals into the differential wire pair</td></tr>
<tr><td><input type="checkbox" class="bom-box" id="d3-resistors" data-lo="1" data-hi="1" aria-label='120 Ω resistors, ¼ W'></td><td><label for="d3-resistors">120 Ω resistors, ¼ W</label></td><td>few</td><td>$1</td><td>any resistor kit</td><td>CAN bus termination</td></tr>
<tr><td><input type="checkbox" class="bom-box" id="d3-psu" data-lo="45" data-hi="60" aria-label='Bench power supply, ≥3 A continuous, adjustable current limit'></td><td><label for="d3-psu">Bench power supply, ≥3 A continuous, adjustable current limit</label></td><td>1</td><td>$45–60</td><td>Amazon (any 30 V/5 A unit)</td><td>Powers the whole bench — run the motor rail at 24 V (12 V is the motor's undervoltage-latch line); the adjustable current limit is smoke insurance</td></tr>
<tr><td><input type="checkbox" class="bom-box" id="d3-multimeter" data-lo="20" data-hi="20" aria-label='Multimeter'></td><td><label for="d3-multimeter">Multimeter</label></td><td>1</td><td>$20</td><td>Amazon</td><td>Non-negotiable — polarity check before every first power-up</td></tr>
<tr><td><input type="checkbox" class="bom-box" id="d3-breadboard" data-lo="10" data-hi="10" aria-label='Breadboard + jumper wires'></td><td><label for="d3-breadboard">Breadboard + jumper wires</label></td><td>1 kit</td><td>$10</td><td>Amazon</td><td>Signals only — power never routes through it</td></tr>
<tr><td><input type="checkbox" class="bom-box" id="d3-usbc" aria-label='USB-C data cable'></td><td><label for="d3-usbc">USB-C data cable</label></td><td>1</td><td>—</td><td>you own one</td><td>Charge-only cables are a classic trap</td></tr>
<tr><td><input type="checkbox" class="bom-box" id="d3-screws" data-lo="10" data-hi="10" aria-label='M2.5 + M3 screw assortment'></td><td><label for="d3-screws">M2.5 + M3 screw assortment</label></td><td>1 box</td><td>$10</td><td>Amazon</td><td>Confirm sizes against the motor drawing</td></tr>
<tr><td><input type="checkbox" class="bom-box" id="d3-usb-can" data-lo="20" data-hi="25" aria-label='USB-to-CAN adapter ("CANable" or clone)'></td><td><label for="d3-usb-can">USB-to-CAN adapter ("CANable" or clone) <span class="bom-optional">optional</span></label></td><td>1</td><td>$20–25</td><td>Amazon</td><td>Lets your laptop eavesdrop on the bus — turns "nothing happens" into evidence. <a href="../03a-wire-the-bench/">Doc 3a</a> shows where it taps in; <a href="../03c-prove-the-bus/">Doc 3c</a> proves your CAN side with it before any motor exists</td></tr>
<tr><td><input type="checkbox" class="bom-box" id="d3-printing" data-lo="20" data-hi="20" aria-label='PETG filament + FDM printer access'></td><td><label for="d3-printing">PETG filament + FDM printer access</label></td><td>~250 g</td><td>$20</td><td>Amazon / local makerspace</td><td>Four printed parts plus three test pieces, ~165 g of frame — a makerspace or print service works. See <a href="../03b-print-the-frame/">Doc 3b</a></td></tr>
<tr><td>—</td><td><label><s>608ZZ bearing, 8 × 22 × 7 mm</s> — <strong>no longer required</strong></label></td><td>0</td><td>$0</td><td>—</td><td>Frame v8 deleted the idle side of the tilt axis: no trunnion, no bearing carrier, no bearing. The head cantilevers off the tilt motor's own output, which carries 0.505 N and 0.0146 N·m — about 3.5% of the motor's peak torque. Kept here, struck through, so anyone who bought one against an earlier revision knows why it is not in the build</td></tr>
<tr><td><input type="checkbox" class="bom-box" id="d3-clamp" data-lo="10" data-hi="10" aria-label='C-clamp or small bench vise'></td><td><label for="d3-clamp">C-clamp or small bench vise</label></td><td>1</td><td>$10</td><td>hardware store</td><td>Clamps the bare motor before its first move</td></tr>
<tr><td><input type="checkbox" class="bom-box" id="d3-payload" aria-label='Payload stand-in: small flashlight or ~100 g weight'></td><td><label for="d3-payload">Payload stand-in: small flashlight or ~100 g weight</label></td><td>1</td><td>—</td><td>—</td><td>Real LED head comes from <a href="../04-full-fixture-bench/">Doc 4</a></td></tr>
<tr><td><input type="checkbox" class="bom-box" id="d3-calipers" data-lo="10" data-hi="20" aria-label='Digital calipers'></td><td><label for="d3-calipers">Digital calipers</label></td><td>1</td><td>$10–20</td><td>Amazon</td><td>The frame chapter (<a href="../03b-print-the-frame/">Doc 3b</a>) runs on measurements</td></tr>
</tbody>
</table>
</div>
<p><button type="button" class="md-button" data-reset>Reset section</button> <button type="button" class="md-button" data-copy>Copy unchecked as shopping list</button></p>
</details>

<details open class="bom-section" data-section="d4" markdown="0">
<summary><strong><a href="../04-full-fixture-bench/">Doc 4 · LED bench (~$170–240)</a></strong> <span class="bom-progress"></span></summary>
<div class="bom-scroll">
<table>
<thead><tr><th></th><th>Part</th><th>Qty</th><th>Est.</th><th>Where</th><th>Why</th></tr></thead>
<tbody>
<tr><td><input type="checkbox" class="bom-box" id="d4-pca9685" data-lo="10" data-hi="30" aria-label='PCA9685 16-ch PWM breakout (Adafruit #815 or clone)'></td><td><label for="d4-pca9685">PCA9685 16-ch PWM breakout (Adafruit #815 or clone)</label></td><td>2</td><td>$30 / ~$10 clones</td><td><a href="https://www.adafruit.com/product/815">Adafruit</a>, Amazon</td><td>The PWM expanders — bridge the A0 jumper on board #2 (address 0x41)</td></tr>
<tr><td><input type="checkbox" class="bom-box" id="d4-uln2803" data-lo="10" data-hi="10" aria-label='ULN2803A driver IC, 18-pin DIP (+ sockets)'></td><td><label for="d4-uln2803">ULN2803A driver IC, 18-pin DIP (+ sockets)</label></td><td>4 (+1 spare)</td><td>$10</td><td><a href="https://www.adafruit.com/product/970">Adafruit #970</a>, Amazon</td><td>Lets 3.3 V dimmer signals switch the 24 V tape channels</td></tr>
<tr><td><input type="checkbox" class="bom-box" id="d4-soldering" data-lo="25" data-hi="40" aria-label='Soldering iron kit (iron, solder, flux, helping hands)'></td><td><label for="d4-soldering">Soldering iron kit (iron, solder, flux, helping hands)</label></td><td>1</td><td>$25–40</td><td>Amazon</td><td>For the tape-pad wires and the address jumper</td></tr>
<tr><td><input type="checkbox" class="bom-box" id="d4-picobuck" data-lo="17.5" data-hi="17.5" aria-label='SparkFun PicoBuck (PRT-13705)'></td><td><label for="d4-picobuck">SparkFun PicoBuck (PRT-13705)</label></td><td>1</td><td>$17.50</td><td><a href="https://www.sparkfun.com/products/13705">sparkfun.com</a></td><td>The spotlight's 3-channel constant-current driver, PWM-dimmable</td></tr>
<tr><td><input type="checkbox" class="bom-box" id="d4-tape" data-lo="486" data-hi="486" aria-label='Diode LED Valent X Tunable White spool (DI-24V-VLX-TW1865-016, 16.4 ft)'></td><td><label for="d4-tape">Diode LED Valent X Tunable White spool (DI-24V-VLX-TW1865-016, 16.4 ft)</label></td><td>1</td><td>$486</td><td><a href="https://buyriteelectric.com/products/diode-led-di-24v-vlx-tw1865-016-16-4ft-4-6w-ft-valent-x-tunable-white-led-tape-light-color-temperature-1800k-3500k-6500k-voltage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">BuyRite</a>, <a href="https://www.lbclightingpro.com/products/diode-led-valent-x-tunable-white-24v-4-6w-ft-16-4-ft-led-tape-light">LBC Lighting</a></td><td>7 short zones ≈ 3.3 ft used — one spool covers everything with spare. Budget bench substitute: <a href="https://www.amazon.com/dp/B08Q3RKCZH">BTF 24 V CCT FCOB</a> (~$30, 2-channel, no 1800 K)</td></tr>
<tr><td><input type="checkbox" class="bom-box" id="d4-star-optics" data-lo="15" data-hi="25" aria-label='Cree 3-up star (XP-G2/XP-L) + Carclo 10507 narrow-spot optic (grab 10508/10509 too)'></td><td><label for="d4-star-optics">Cree 3-up star (XP-G2/XP-L) + Carclo 10507 narrow-spot optic (grab 10508/10509 too)</label></td><td>1</td><td>$15–25 (optics $3 ea)</td><td><a href="https://www.ledsupply.com">LEDSupply</a></td><td>The spotlight payload — optics snap-swap in seconds, which <em>is</em> the beam-width experiment. <strong>Check the dies are electrically isolated</strong> (own pads each): stock 3-ups are usually series-wired and cannot be driven per channel</td></tr>
<tr><td><input type="checkbox" class="bom-box" id="d4-heatsink" data-lo="8" data-hi="8" aria-label='Heatsink ≥2"×2" + thermal adhesive'></td><td><label for="d4-heatsink">Heatsink ≥2"×2" + thermal adhesive</label></td><td>1</td><td>$8</td><td>Amazon</td><td>The star cooks itself bare in under a minute — never run unmounted</td></tr>
<tr><td><input type="checkbox" class="bom-box" id="d4-wago" data-lo="15" data-hi="15" aria-label='WAGO 221 lever-nut assortment'></td><td><label for="d4-wago">WAGO 221 lever-nut assortment</label></td><td>1 pack</td><td>$15</td><td>Amazon, Home Depot</td><td>24 V power distribution — high current stays off the breadboard</td></tr>
<tr><td><input type="checkbox" class="bom-box" id="d4-fuse" data-lo="7" data-hi="7" aria-label='Inline fuse holder (5x20 mm) + T3.15AL250V slow-blow fuses'></td><td><label for="d4-fuse">Inline fuse holder (5×20 mm) + <strong>T3.15AL250V</strong> slow-blow fuses</label></td><td>1</td><td>$7</td><td>Amazon</td><td>Cheap insurance on the 24 V rail. <strong>Time-delay, not fast-acting.</strong> 3.15 A is the standard IEC value that <em>is</em> "3 A" — there is no 3.00 A in this family. Buy a few <strong>T4AL250V</strong> at the same time: that's the fuse you step to if you ever run 2× tape</td></tr>
<tr><td><input type="checkbox" class="bom-box" id="d4-buck" data-lo="7.95" data-hi="7.95" aria-label='Pololu D24V22F5 buck (24 V→5 V, 2.5 A)'></td><td><label for="d4-buck">Pololu D24V22F5 buck (24 V→5 V, 2.5 A)</label></td><td>1</td><td>$7.95</td><td><a href="https://www.pololu.com/product/2858">pololu.com/product/2858</a></td><td>Fixed 5 V, nothing to mis-adjust</td></tr>
<tr><td><input type="checkbox" class="bom-box" id="d4-wire" data-lo="20" data-hi="20" aria-label='10 kilohm resistors 1/4 W, 22 AWG solid-core signal wire, 18-20 AWG stranded for 24 V runs, extra breadboard'></td><td><label for="d4-wire">10 kΩ resistors <strong>¼ W</strong> · 22 AWG <strong>solid-core</strong> signal wire · 18–20 AWG <strong>stranded</strong> for 24 V runs · extra breadboard</label></td><td>—</td><td>$20</td><td>Amazon</td><td>Three jobs, and the wire is different for each. The 10 kΩ are the PicoBuck IN pulldowns — ~1 mW each, so ¼ W is 200× margin and the smaller body crowds the board less. Signal wire must be <strong>solid</strong> to hold in breadboard contacts. The 24 V feeds are <strong>stranded</strong> because they get handled. <strong>Correction to an earlier version of this row:</strong> it said a ULN output feeding a tape zone "carries amps, not milliamps." It does not. This build's seven zones share ~3.3 ft of 4.6 W/ft tape, so a zone is about <strong>90 mA</strong> — 24 AWG is fine for them. The number to respect is the ULN2803's own 500 mA per-channel ceiling</td></tr>
</tbody>
</table>
</div>
<p><button type="button" class="md-button" data-reset>Reset section</button> <button type="button" class="md-button" data-copy>Copy unchecked as shopping list</button></p>
</details>
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

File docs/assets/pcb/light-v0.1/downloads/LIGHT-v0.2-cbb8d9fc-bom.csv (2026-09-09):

Item | Designators | Quantity per board | Quantity for 2 prototypes (no attrition) | Value / description | Manufacturer | Manufacturer part number | KiCad footprint | Primary source | Source revision / context | Assembly / engineering note | Sourcing evidence URL | Order status
1 | U1 | 1 | 2 | ESP32-C6-WROOM-1-N8 | Espressif | ESP32-C6-WROOM-1-N8 | EL:ESP32-C6-WROOM-1 | https://documentation.espressif.com/esp32-c6-wroom-1_wroom-1u_datasheet_en.pdf | Exact selection for cbb8d9fc grouped arm connectors and branding; supplier processes not approved. | 3.3V supply; antenna keepout and peak-current/decoupling verification required | https://documentation.espressif.com/esp32-c6-wroom-1_wroom-1u_datasheet_en.pdf | QUOTE ONLY - exact source/quantity/process not confirmed
2 | R1, R2, R3, R4, R5, R6, R20, R21, R36, R40, R41, R502, R504, R506, R507, R508, R509, R512, R513, R518, R519, R520 | 22 | 44 | 10k | Yageo | RC0603FR-0710KL | Resistor_SMD:R_0603_1608Metric | https://www.yageogroup.com/component-documentation/download/specsheet/RC0603FR-0710KL | Exact selection for cbb8d9fc grouped arm connectors and branding; supplier processes not approved. | 0.1W0603 or0.125W0805 at70C; exact value/code checked; assembler must confirm available quantity | https://www.yageogroup.com/component-documentation/download/specsheet/RC0603FR-0710KL | QUOTE ONLY - exact source/quantity/process not confirmed
3 | R526, R527, R528 | 3 | 6 | 910 ohm 1% | Yageo | RC0603FR-07910RL | Resistor_SMD:R_0603_1608Metric | https://www.yageogroup.com/component-documentation/download/specsheet/RC0603FR-07910RL | Exact selection for cbb8d9fc grouped arm connectors and branding; supplier processes not approved. | Required with U5 Schmitt replacement; do not fit the old 10k on R526-R528. | https://www.yageogroup.com/component-documentation/download/specsheet/RC0603FR-07910RL | QUOTE ONLY - exact source/quantity/process not confirmed
4 | C1, C22, C42, C43, C508 | 5 | 10 | 1u / 1uF 25V X7R | TDK | C1608X7R1E105K080AB | Capacitor_SMD:C_0603_1608Metric | https://product.tdk.com/en/search/capacitor/ceramic/mlcc/info?part_no=C1608X7R1E105K080AB | Exact selection for cbb8d9fc grouped arm connectors and branding; supplier processes not approved. |  | https://product.tdk.com/en/search/capacitor/ceramic/mlcc/info?part_no=C1608X7R1E105K080AB | QUOTE ONLY - exact source/quantity/process not confirmed
5 | R7, R8, R301, R302, R303, R304, R305, R306, R307, R308, R309, R310, R311, R312, R313, R314, R315, R316, R317, R318, R319, R320, R321 | 23 | 46 | 2.2k | Yageo | RC0603FR-072K2L | Resistor_SMD:R_0603_1608Metric | https://www.yageogroup.com/component-documentation/download/specsheet/RC0603FR-072K2L | Exact selection for cbb8d9fc grouped arm connectors and branding; supplier processes not approved. | 0.1W0603 or0.125W0805 at70C; exact value/code checked; assembler must confirm available quantity | https://www.yageogroup.com/component-documentation/download/specsheet/RC0603FR-072K2L | QUOTE ONLY - exact source/quantity/process not confirmed
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

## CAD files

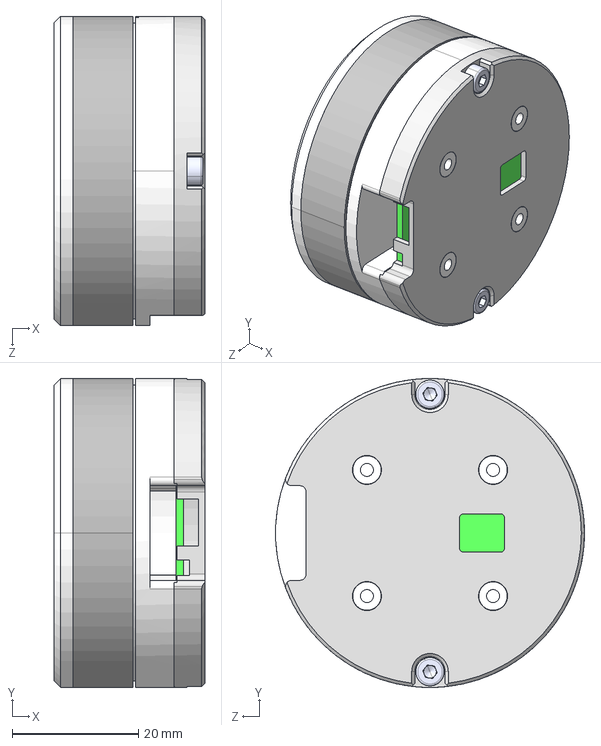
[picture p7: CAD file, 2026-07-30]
ref/RMD-L-5005-S.STEP
23.9 x 49.0 x 49.0 mm

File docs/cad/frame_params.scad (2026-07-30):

// =============================================================================
// frame_params.scad · Engineered Lighting — every number the frame is built from
// v8 (2026-07-30)  — ground-up rebuild
// =============================================================================
// BOTH frame.scad and assembly.scad `include` this file. That is the whole
// anti-drift mechanism: there is exactly one copy of every dimension, and the
// assembly view cannot disagree with the parts you print.
//
// PROVENANCE IS PART OF THE DATA. Every number below is tagged:
//
//   [STEP]    measured out of ref/RMD-L-5005-S.STEP by ref/step_dump.py.
//             These are face boundaries in the vendor's own solid model.
//   [MANUAL]  RMD-L Series Servo Actuator User Manual Rev 1.01, section 2.1.
//   [DRAWING] LEDdynamics DLH-3UP-EH assembly drawing Rev A.
//   [STD]     a published standard (thread series, bearing series).
//   [CHOICE]  a design decision of mine. Change it freely.
//   [MEASURE] you must measure it. The design tolerates a range, stated.
//   [UNVERIFIED] nobody publishes it. What the design does about that is
//             written next to it.
//
// v8 deleted the idle side of the tilt axis entirely — no trunnion, no bearing
// carrier, no 608, six fewer screws, one fewer yoke arm. The head cantilevers
// off the tilt motor's own output. The load numbers that justify that are in
// the CANTILEVER LOAD CASE block near the bottom, and they are echoed on every
// render so they cannot quietly stop being true.
// =============================================================================

cad_version = "v8";   // frame.scad and assembly.scad both echo this on load.
                      // If it prints `undef`, your frame_params.scad is not the
                      // one these files were written against — see the note in
                      // docs/03b-print-the-frame.md about stale copies.

// =============================================================================
// MOTOR — MyActuator RMD-L-5005, "S" bore variant
// =============================================================================
// Everything in this block is [STEP] unless marked otherwise, and five of the
// numbers are independently confirmed by [MANUAL]: D49, 23.9 long, 4 x M3 on
// D25, 4 x M2.5 on 20x20, D8.1 bore. That agreement is why the rest is trusted.
// Full write-up, including how it was parsed: ref/RMD-L-5005-S.md
motor_d        = 49;    // [STEP] body OD. Also the max radius ANYWHERE: R24.5.
motor_len      = 23.9;  // [STEP] output face to rear face

// --- the output end (this whole face rotates) -------------------------------
// The output rotor is a separate solid body in the STEP from the housing, and
// the housing does not begin until 3.0 mm back from the output face. So a plate
// laid on the output face turns with it, and has 3 mm of axial room at full D49
// before it touches the stator and clamps the motor solid.
out_flat_od    = 47;    // [STEP] flat annulus OD. Beyond this is the chamfer.
out_flat_id    = 10.1;  // [STEP] ...and its ID, the mouth of the bore chamfer
out_chamfer    = 1;     // [STEP] 45 deg, D47 -> D49 over the first 1.0 mm
stator_x       = 3.0;   // [STEP] ** the stationary housing starts here **
out_bcd        = 25;    // [STEP][MANUAL] output bolt circle
out_bolt_n     = 4;     // [STEP][MANUAL]
out_bolt_d     = 3;     // [STEP][MANUAL] M3 (D2.5 tap drill in the model)
out_bolt_a0    = 45;    // [CHOICE] turn the output so TWO holes clear the head's
                        // split line. At 0 only one does, and the head needs two.
// ** THE SINGLE MOST CONSTRAINING NUMBER IN THE WHOLE DESIGN **
// The tapped holes are 2.5 mm deep and they BREAK THROUGH into the rotor's
// internal cavity at x = 2.5 (the cavity floor is a D17..D42.2 face at exactly
// that plane). A screw longer than the hole does not bottom on metal, it enters
// the motor. Every M3 length in this design is derived from this number.
out_thread_depth = 2.5; // [STEP]
out_thread_use   = 2.3; // [CHOICE] what we actually allow ourselves to use, so
                        // there is 0.2 mm of air under every screw tip.
// If the vendor simplified the thread in the STEP and the real hole is deeper,
// a short screw still works perfectly. The error is one-sided and safe.

// --- there is no boss -------------------------------------------------------
// [STEP] Settled, not guessed: the output face is a flat annulus and it is the
// frontmost plane of the entire motor. Stand-proud is 0.000 mm. The parameter
// survives so that every dependent dimension still DERIVES from it — if you
// ever fit a different actuator that does have a boss, set these two and the
// recess, the mate plane and the span all follow. At 0 they vanish.
out_boss_d     = 0;     // [STEP] no boss exists
out_boss_h     = 0;     // [STEP] 0.000 mm proud
// A quarter of the boss height, capped at 1 mm. Never let this reach out_boss_h:
// a part that bottoms on the STATOR face clamps the motor solid.
boss_recess    = min(1, out_boss_h / 4);

// --- the rear end (this is what you bolt to) --------------------------------
rear_sq        = 20;    // [STEP][MANUAL] the rear mount is a 20 x 20 SQUARE
rear_bolt_n    = 4;     // [STEP][MANUAL]
rear_bolt_d    = 2.5;   // [STEP][MANUAL] M2.5. NOT M4, and NOT on D43.
rear_bolt_a0   = 45;    // ...which as a bolt CIRCLE is rear_sq*sqrt(2) at 45 deg
rear_bcd       = rear_sq * sqrt(2);   // 28.284
rear_thread_depth = 10.7;  // [STEP] x 13.2 -> 23.9. Generous, unlike the front.
// The motor's OWN cover screws: D4.5 heads on a D44 circle, sunk only 0.300 mm
// below the rear face. A flat plate clears them by 0.3 mm — so never put a
// raised pad or spigot on the rear-mating side of a plate near D44.
cover_head_bcd = 44;    // [STEP]
cover_head_d   = 4.5;   // [STEP]
cover_head_sunk = 0.3;  // [STEP] how far below the rear face the heads sit

shaft_bore_d   = 8.1;   // [STEP][MANUAL] "S" variant. The "L" is 12.7 and is a
                        // mechanically different part — do not mix the STEPs.

// --- the connectors ---------------------------------------------------------
// [STEP] Nothing on this motor protrudes past its own barrel: the maximum
// radius of any vertex in the model is exactly R24.5, checked band by band
// along the full 23.9 mm. The connectors are RECESSES cut into the casting,
// the deepest reaching only R23.16.
connector_protrusion = 0;  // [STEP] the motor itself needs no radial clearance
// [UNVERIFIED] BUT the mating cable plug is not in the STEP, and a plug pushed
// into those cavities will stand out, as will the cable's bend radius. Nobody
// publishes that figure. So the design does not assume zero: it keeps a stated
// radial gap at the connector azimuth and tells you to turn the connector into
// it at build time. If your plug is fatter than this, turn the motor, don't
// file the frame.
connector_plug_clear = 8;  // [CHOICE] radial air kept clear outside D49

motor_mass     = 92;    // [MANUAL] g, each
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

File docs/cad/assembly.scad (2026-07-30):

// =============================================================================
// assembly.scad · Engineered Lighting — robotic spotlight, THE WHOLE MACHINE
// v8 (2026-07-30)
// =============================================================================
//
//   include <frame_params.scad>   <- the same single copy of every dimension
//   use     <frame.scad>          <- the real printed parts, as modules only
//
// `use` imports the part modules without running frame.scad's own render block,
// so this file draws the assembly and only the assembly.
//
// IF THE VERSION BANNER BELOW PRINTS `undef`, STOP. Your frame_params.scad is
// not the one these files were written against, and OpenSCAD will quietly
// collapse the missing names to undef, drop the geometry they position, write
// a valid-looking STL and exit 0. That is how you get "only some of the parts
// render". Work in the repo, not in a downloads folder with older copies.
//
//   view  = assembled | exploded
//   pan / tilt / slide            pose it
//   show_cap = false              look inside the clamp
//   clip = none | front | side    section it
//
// Colours: gold = base plate · orange = yoke · teal = head · grey = bought
// =============================================================================

include <frame_params.scad>
use <frame.scad>

/* [Pose] */
view  = "assembled";  // [assembled, exploded]
pan   = 0;            // [-180:5:180]
tilt  = 0;            // [-90:5:90]
slide = 0;            // [-4:0.5:4]
/* [Show] */
show_bolts = true;
show_wires = true;
show_bench = true;
show_cap   = true;
show_beam  = false;
clip       = "none";  // [none, front, side]

$fn = 48;
ep = 0.01;

echo(str(cad_version, " assembly · if this says undef you have a mismatched file set"));

e       = (view == "exploded") ? 1 : 0;
E_BENCH = 90 * e;  E_PLATE = 34 * e;  E_PANM = 20 * e;  E_YOKE = 76 * e;
E_TILTM = 46 * e;  E_HEAD  = 40 * e;  E_CAP  = 58 * e;  E_BOLT = 18 * e;
E_HOUS  = 24 * e;   // payload lifts OUT of the saddle, upward, and less far
                    // than the cap so the order reads: cap off, housing out.

// ONE assembly frame, stated once. z_tilt is a YOKE-LOCAL coordinate (the
// yoke's origin is its bridge TOP face); the yoke hangs at z = -motor_len.
// Conflating those two frames is what made the first run of checks.scad report
// six collisions that were not there.
yoke_z     = -motor_len;
z_tilt_asm = yoke_z + z_tilt;

// ------------------------------------------------------------------ bought --
module screw(d = 3, len = 12, hd = m3_head_d, hh = m3_head_h) {
  color("#33343a") { cylinder(d = hd, h = hh); translate([0, 0, -len]) cylinder(d = d, h = len + ep); }
}
// heads at z = 0, driven -Z
module screw_ring(bcd, n, a0, len, d = 3, hd = m3_head_d, hh = m3_head_h) {
  for (i = [0 : n - 1]) rotate([0, 0, a0 + i * 360 / n])
    translate([bcd / 2, 0, 0]) screw(d, len, hd, hh);
}

// The motor, drawn from the STEP's real numbers: a flat D47 output annulus, a
// 1 mm 45 deg chamfer out to D49, and NO BOSS. Origin = the OUTPUT FACE, body
// running -Z, so it meets a printed part exactly as the real one does.
module rmd_motor() {
  difference() {
    union() {
      color("#b8bcc3") {
        rotate([180, 0, 0]) {
          cylinder(d1 = out_flat_od, d2 = motor_d, h = out_chamfer);
          translate([0, 0, out_chamfer]) cylinder(d = motor_d, h = motor_len - out_chamfer);
        }
      }
      // the connectors are RECESSES in the real casting, so nothing is drawn
      // standing out of the barrel. Nothing on this motor exceeds D49.
    }
    translate([0, 0, ep]) cylinder(d = shaft_bore_d, h = motor_len + 2, center = true);
    // the output's tapped holes, 2.5 mm deep, breaking into the rotor cavity
    translate([0, 0, -out_thread_depth])
      for (i = [0 : out_bolt_n - 1]) rotate([0, 0, out_bolt_a0 + i * 360 / out_bolt_n])
        translate([out_bcd / 2, 0, 0]) cylinder(d = out_bolt_d - 0.5, h = out_thread_depth + ep);
  }
  // The rear square's tapped holes are INSIDE the casting; drawing them as
  // solid cylinders inside the body just makes coincident surfaces and a
  // z-fighting starburst on the rear face. They are not drawn.
}

// DLH-3UP-EH. Beam fires +Y; barrel axis along Y. Not finned — four channels
// cut into a smooth sleeve — so the drawn diameter is the real clamped one.
module led_housing() {
  rotate([-90, 0, 0]) {
    color("#9aa0a9") {
      difference() {
        cylinder(d = payload_od, h = payload_body, center = true);
        for (i = [0 : 3]) rotate([0, 0, i * 90])
          translate([payload_od / 2, 0, 0]) cube([1.2, 3, payload_body + 2], center = true);
      }
      translate([0, 0, -payload_body / 2 - payload_stub_l])
        cylinder(d = payload_stub_d, h = payload_stub_l + ep);
    }
    color("#34363c") translate([0, 0, payload_body / 2 - 3]) cylinder(d = payload_od - 4.4, h = 3);
    color("#f4ecc9") for (i = [0 : 2]) rotate([0, 0, i * 120 + 30])
      translate([4.7, 0, payload_body / 2 - 1.4]) cube([3.4, 3.4, 0.9], center = true);
    if (show_beam) color("#fff3c4", 0.13)
      translate([0, 0, payload_body / 2]) cylinder(d1 = 16, d2 = 74, h = 120);
  }
}

module c_clamp() {
  color("#4a4d54") {
    translate([-9, -30, -10]) cube([18, 30, 10]);
    translate([-9, -30, t_plate]) cube([18, 30, 10]);
    translate([-9, -2, -10]) cube([18, 10, t_plate + 20]);
    translate([0, -18, -21]) cylinder(d = 6.5, h = 12);
    translate([0, -18, -27]) cylinder(d = 17, h = 5.5);
  }
}
// The bench edge. The machine hangs OFF it: only the aft tongue lands on the
// bench, and the hub — with the pan motor and everything under it — overhangs
// the edge. So the bench must stop short of the hub, not run under it.
bench_edge_y = -(hub_r + 3);
module bench() {
  color("#c9a678") translate([-90, bench_edge_y - 130, -16]) cube([180, 130, 16]);
}

module wire(pts, d = 4.6) {
  color("#26262b") for (i = [0 : len(pts) - 2]) hull() {
    translate(pts[i]) sphere(d = d); translate(pts[i + 1]) sphere(d = d); }
}
module guide(a, b) {
  color("#9a9a9a", 0.8) hull() { translate(a) sphere(d = 1.1); translate(b) sphere(d = 1.1); }
}

// =============================================================================
//                                   SCENE
// world: pan axis = Z · tilt axis = X · beam fires +Y · plate's mating face z=0
// =============================================================================
module scene() {

  // 1 · bench and C-clamp, gripping the base plate's aft tongue
  if (show_bench) translate([0, 0, -E_BENCH]) {
    bench();
    translate([0, bench_edge_y - 14, 0]) c_clamp();
  }

  // 2 · base plate
  translate([0, 0, E_PLATE]) {
    color("#d8a93a") base_plate();
    if (show_bolts) translate([0, 0, t_plate - m25_head_h + E_BOLT])
      screw_ring(rear_bcd, rear_bolt_n, rear_bolt_a0, t_plate + 8,
                 rear_bolt_d, m25_head_d, m25_head_h);
  }

  // 3 · pan motor, hanging under the plate: REAR up, OUTPUT down
  translate([0, 0, -E_PANM]) rmd_motor();

  // ------------------------------------------------------------ pan group ---
  rotate([0, 0, pan]) translate([0, 0, yoke_z - E_YOKE]) {

    color("#e8862a") yoke();

    // 4 · four M3 up through the bridge into the pan output. M3 x 10: the
    //     tapped hole is 2.5 mm deep and opens into the rotor, so a longer
    //     screw bottoms and never clamps.
    if (show_bolts) translate([0, 0, -t_bridge - E_BOLT]) rotate([180, 0, 0])
      screw_ring(out_bcd, out_bolt_n, out_bolt_a0, out_screw_len(t_bridge));

    // 5 · tilt motor on the arm's INNER face, output facing +X (inboard)
    translate([arm_in + E_TILTM, 0, z_tilt]) rotate([0, 90, 0]) rmd_motor();
    // ...bolted from OUTSIDE the arm, so a driver reaches the heads
    if (show_bolts) translate([arm_out - E_BOLT - E_TILTM, 0, z_tilt]) rotate([0, -90, 0])
      screw_ring(rear_bcd, rear_bolt_n, rear_bolt_a0, t_arm + rear_thread_depth - 2,
                 rear_bolt_d, m25_head_d, m25_head_h);

    // ------------------------------------------------------- head group ----
    translate([0, 0, z_tilt]) rotate([tilt, 0, 0]) translate([E_HEAD, 0, 0]) {

      color("#39c0bd") translate([out_face_x, 0, 0]) cradle();

      // 6 · the two output-flange bolts a driver can reach: the ones above the
      //     split line, driven while the cap is still off. M3 x 10.
      if (show_bolts) translate([out_face_x + cr_wall + E_BOLT, 0, 0])
        for (i = [0 : out_bolt_n - 1]) if (out_bolt_up(i))
          rotate([out_bolt_a0 + i * 360 / out_bolt_n, 0, 0])
            translate([0, 0, out_bcd / 2]) rotate([0, 90, 0])
              screw(3, out_screw_len(cr_wall));
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

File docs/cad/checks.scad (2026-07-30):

// =============================================================================
// checks.scad · Engineered Lighting — the frame's boolean test suite
// =============================================================================
// Driven by tools/run_checks.py, which renders each check to an STL and
// measures its volume. OpenSCAD writes NO FILE AT ALL when a result is empty,
// and for most of these checks that is the pass condition.
//
// TWO KINDS OF CHECK, and they read in opposite directions:
//
//   hole:*   A HOLE THAT MUST EXIST. The probe is the ideal hole. It is
//            intersected with the FINISHED part, so:
//                empty  -> the material really was removed -> PASS
//                solid  -> the cut missed and the hole is not there -> FAIL
//            This is the inversion that catches the defect v7 shipped and that
//            I then shipped again in the yoke's arm: a cut whose coordinates
//            put it outside the part removes nothing, changes no mass, and
//            renders as a clean solid. Nothing but a boolean sees it.
//
//   clash:*  TWO THINGS THAT MUST NOT TOUCH. Straight intersection of the two,
//            positioned exactly as the assembly positions them:
//                empty  -> PASS
//                solid  -> collision, and the volume says how bad
//
// Everything is positioned from frame_params.scad, so a check cannot drift
// away from the geometry it is checking.
// =============================================================================

include <frame_params.scad>
use <frame.scad>

check = "none";
$fn = 64;
ep = 0.01;

// -----------------------------------------------------------------------------
// probes — the ideal shape of each hole that must exist
// -----------------------------------------------------------------------------

// the two reachable output-flange bolts through the cradle's motor-side plate
module probe_cradle_out_bolts() {
  for (i = [0 : out_bolt_n - 1]) if (out_bolt_up(i))
    rotate([out_bolt_a0 + i * 360 / out_bolt_n, 0, 0])
      translate([0, 0, out_bcd / 2]) rotate([0, 90, 0])
        translate([0, 0, 0.5]) cylinder(d = m3_clear_x - 0.6, h = cr_wall - 1);
}

// the tilt motor's wire path through the cradle's plate
module probe_cradle_wire() {
  translate([0.5, 0, 0]) rotate([0, 90, 0])
    cylinder(d = wire_hole_d - 3, h = cr_wall - 1);
}

// the tilt motor's rear bolt square through the yoke's arm
module probe_yoke_arm_bolts() {
  translate([0, 0, z_tilt])
    for (i = [0 : rear_bolt_n - 1])
      rotate([rear_bolt_a0 + i * 360 / rear_bolt_n, 0, 0])
        translate([0, 0, rear_bcd / 2]) rotate([0, 90, 0])
          translate([0, 0, arm_out + 0.5]) cylinder(d = m25_clear_x - 0.5, h = t_arm - 1);
}

// the tilt motor's wire path through the arm
module probe_yoke_arm_wire() {
  translate([arm_out + 0.5, 0, z_tilt]) rotate([0, 90, 0])
    cylinder(d = wire_hole_d - 4, h = t_arm - 1);
}

// the pan output bolts through the bridge
module probe_yoke_bridge_bolts() {
  translate([0, 0, -t_bridge + 0.5])
    bolt_ring_probe(out_bcd, m3_clear - 0.6, out_bolt_n, t_bridge - 1, out_bolt_a0);
}
module bolt_ring_probe(bcd, d, n, h, a0 = 0) {
  for (i = [0 : n - 1]) rotate([0, 0, a0 + i * 360 / n])
    translate([bcd / 2, 0, 0]) cylinder(d = d, h = h);
}

// the pan motor's rear bolts through the base plate
module probe_plate_bolts() {
  translate([0, 0, 0.5]) bolt_ring_probe(rear_bcd, m25_clear - 0.5, rear_bolt_n,
                                         t_plate - 1, rear_bolt_a0);
}

// the pan motor's wire path through the base plate
module probe_plate_wire() {
  translate([0, 0, 0.5]) cylinder(d = wire_hole_d - 3, h = t_plate - 1);
}

// the clamp screws through the cap
module probe_cap_screws() {
  for (sx = [-1, 1], sy = [-1, 1])
    translate([cr_wall + blk_in + sx * cap_bolt_x, sy * cap_bolt_y / 2,
               -axis_z + clamp_nip + 0.5])
      cylinder(d = m3_clear - 0.6, h = cap_z - clamp_nip - 1);
}

// -----------------------------------------------------------------------------
// assembly placement — one definition, used by every clash check
// -----------------------------------------------------------------------------
// ONE assembly frame, defined once. z_tilt is a YOKE-LOCAL coordinate (the
// yoke's own origin is its bridge TOP face), and the yoke itself is placed at
// z = -motor_len. Using z_tilt directly as an assembly coordinate puts the head
// motor_len too high and every head-vs-yoke clash fires spuriously — which is
// exactly what happened on the first run of this suite. Same class as reading a
// centre of mass in the wrong frame, which is in the defect log.
yoke_z     = -motor_len;              // yoke local z=0 -> assembly z
z_tilt_asm = yoke_z + z_tilt;         // the tilt axis, in ASSEMBLY coordinates

module at_tilt_motor()  { translate([out_face_x, 0, z_tilt_asm]) children(); }
module at_head(t = 0)   { translate([out_face_x, 0, z_tilt_asm]) rotate([t, 0, 0]) children(); }

// the tilt motor sits with its OUTPUT FACE at out_face_x, body running -X
module tilt_motor_at()  { at_tilt_motor() motor_solid_local(); }
module tilt_stator_at() { at_tilt_motor() motor_stator_local(); }
// local copies so checks.scad does not depend on frame.scad's `use` scope
module motor_solid_local() {
  rotate([0, -90, 0]) difference() {
    union() {
      cylinder(d1 = out_flat_od, d2 = motor_d, h = out_chamfer);
      translate([0, 0, out_chamfer]) cylinder(d = motor_d, h = motor_len - out_chamfer);
    }
    translate([0, 0, -ep]) cylinder(d = shaft_bore_d, h = motor_len + 1);
  }
}
module motor_stator_local() {
  rotate([0, -90, 0]) translate([0, 0, stator_x])
    cylinder(d = motor_d, h = motor_len - stator_x);
}
// the pan motor hangs under the base plate: rear face at z = 0, output at -motor_len
module pan_motor_at() { translate([0, 0, yoke_z]) motor_solid_local_z(); }
module motor_solid_local_z() {
  difference() {
    union() {
      cylinder(d1 = out_flat_od, d2 = motor_d, h = out_chamfer);
      translate([0, 0, out_chamfer]) cylinder(d = motor_d, h = motor_len - out_chamfer);
    }
    translate([0, 0, -ep]) cylinder(d = shaft_bore_d, h = motor_len + 1);
  }
}

// the payload, in the saddle
module payload_at() {
  translate([out_face_x + cr_wall + blk_in, 0, z_tilt_asm - axis_z]) rotate([90, 0, 0])
    cylinder(d = payload_od + payload_tol, h = payload_len, center = true);
}

// the yoke sits below the pan motor: its bridge TOP face at z = -motor_len
module yoke_at() { translate([0, 0, yoke_z]) yoke(); }
module cradle_at(t = 0) { at_head(t) cradle(); }
module cap_at(t = 0)    { at_head(t) cradle_cap(); }

// =============================================================================
// DISPATCH
// =============================================================================

// --- holes that must exist (expect EMPTY) ---
if      (check == "hole:cradle_out_bolts") intersection() { cradle(); probe_cradle_out_bolts(); }
else if (check == "hole:cradle_wire")      intersection() { cradle(); probe_cradle_wire(); }
else if (check == "hole:yoke_arm_bolts")   intersection() { yoke();   probe_yoke_arm_bolts(); }
else if (check == "hole:yoke_arm_wire")    intersection() { yoke();   probe_yoke_arm_wire(); }
else if (check == "hole:yoke_bridge_bolts")intersection() { yoke();   probe_yoke_bridge_bolts(); }
else if (check == "hole:plate_bolts")      intersection() { base_plate(); probe_plate_bolts(); }
else if (check == "hole:plate_wire")       intersection() { base_plate(); probe_plate_wire(); }
else if (check == "hole:cap_screws")       intersection() { cradle_cap(); probe_cap_screws(); }
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

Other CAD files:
docs/cad/frame.scad
docs/cad/render-test.scad

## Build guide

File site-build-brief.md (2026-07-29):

# Build Brief · engineering.engineered.lighting

*Paste this into Claude Code (plan mode) from the folder containing the 7 series docs + wiring SVGs/PNGs. It contains everything needed to plan and build the site.*

## Goal

Turn the Engineered Lighting prototype series (7 markdown docs + 4 wiring diagrams, in this folder) into a static instruction-manual website hosted at **engineering.engineered.lighting**. It should read like a book: landing page → chapters → next/prev, with search. Adding a future doc must be as simple as dropping a markdown file in a folder.

## Stack (decided — don't relitigate unless something breaks)

- **MkDocs + Material theme** (`pip install mkdocs-material`). Python-only toolchain, one `mkdocs.yml`.
- Auto page discovery: use filename-prefix ordering (`01-…` … `07-…`) with either explicit `nav:` or the `mkdocs-awesome-pages` plugin so a new `08-whatever.md` becomes a page without editing config.
- Deploy: **GitHub Pages** via the standard `mkdocs gh-deploy` GitHub Action (or Cloudflare Pages if the domain's DNS is on Cloudflare — builder's choice, prefer whichever matches where `engineered.lighting`'s DNS lives).
- Custom domain: `CNAME` file containing `engineering.engineered.lighting` + a DNS CNAME record `engineering` → the pages host. HTTPS via the host's cert automation.

## Site structure

```
docs/
  index.md                  ← LANDING PAGE (see spec below)
  bom-checklist.md          ← INTERACTIVE CHECKLIST (see spec below)
  01-how-we-got-here.md     ← from robotic-spotlight-gimbal-research.md
  02-choosing-the-motors.md ← from robotic-spotlight-micro-gimbal-research.md
  03-build-the-gimbal.md    ← from gimbal-breadboard-prototype-plan.md
  04-full-fixture-bench.md  ← from combined-bench-prototype-plan.md
  05-teach-it-to-aim.md     ← from spatial-intelligence-architecture.md
  06-message-contract.md    ← from system-message-contract.md
  07-building-the-software.md ← from software-build-plan.md
  assets/                   ← the 4 wiring-*.svg (+ .png fallbacks)
mkdocs.yml
```

Porting rules: keep doc content byte-faithful except (a) fix image paths to `assets/`, (b) convert each doc's "The series:" nav blockquote into nothing (the site sidebar replaces it), (c) the per-doc BoM tables STAY in the docs *and* feed the checklist page. Material's right-hand TOC turns each doc's `##` stages into chapter navigation automatically — do not split docs into multiple pages in v1.

## Landing page spec (index.md)

1. Hero: "Engineered Lighting · Engineering Notebook" + one-paragraph vision (source: Doc 1's "The project, in one paragraph" — reuse verbatim).
2. "What we're building toward" — 3 short cards: the silent robotic spotlight (Docs 1–4), the aiming intelligence (Doc 5), the system architecture (Docs 6–7).
3. Prominent link card → **BoM checklist**.
4. The document map table from Doc 1 (7 rows, with budget column), each row linking to its page.
5. Status line: total prototype budget ~$475–850/room; current phase: parts ordering / bench build.

## Interactive BoM checklist spec (bom-checklist.md)

- One page, three collapsible sections mirroring the three BoMs: **Doc 3 · Gimbal (~$185–290)**, **Doc 4 · LED bench (~$170–240)**, **Doc 5 · Per-room perception (~$120–320)**. Source the item rows from each doc's BoM table — item name, qty, est. price, source, and the one-line purpose note.
- Each item = a real checkbox. Persist state in `localStorage` (key: `el-bom-v1`, per-item stable IDs like `d3-motors`). Survives reload; no backend.
- Progress indicators: per-section "6/12 · ~$142 checked" and a global progress bar. A "reset section" and "copy unchecked as shopping list" button (copies plain text to clipboard).
- Implementation: plain HTML/JS inside the markdown page (Material allows raw HTML; put the ~80 lines of JS in `docs/js/checklist.js` via `extra_javascript`). No framework.
- Honest note at top: prices were verified July 2026 — re-check live prices when ordering (this rule is *in the docs* — surface it here).

## Acceptance checklist

- [ ] `mkdocs serve` renders all 7 chapters with diagrams visible, sidebar ordered 01→07, search working
- [ ] Landing page reads as a coherent front door; every link resolves
- [ ] Checklist: check 3 items → reload → still checked; reset works; progress math correct
- [ ] New-doc test: add `08-test.md` with a title → appears in nav without touching `mkdocs.yml`
- [ ] Deployed to the pages host; `engineering.engineered.lighting` resolves with HTTPS (DNS step may be manual — print the exact record to add)
- [ ] Mobile: chapters and checklist usable on a phone at the workbench

## Nice-to-haves (only after acceptance passes)

Dark mode toggle (Material built-in — just enable), a "print chapter" CSS tweak for bench printouts, per-chapter "Done when" checkboxes using the same localStorage pattern, and an RSS-less "changelog" page appended per session of edits.

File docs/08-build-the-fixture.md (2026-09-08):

---
title: 8 · Build the Fixture
description: "Hand-solder the proven bench architecture onto stacked round protoboards inside an E26-fed fixture body — six wiring steps, each with a diagram, a done-when, and an if-stuck."
---

# Doc 8 · Build the Fixture — From Breadboard to a Thing That Screws In

**Engineered Lighting prototype series · July 2026**
The bench taught the architecture; this chapter makes it permanent. Nothing
new runs here — the YAML, the entities, and the scenes come along unchanged
from [Doc 4](04-full-fixture-bench.md). Every load ends in a plug and every
module sits in a socket, so nothing in this build is a one-way door.

> **The one gate before you start:** [Doc 4](04-full-fixture-bench.md)
> stage 7's checklist passes on the breadboard. Solder freezes a *validated*
> design.

## Concepts (plain English)

- **Trunk:** one thick solid wire soldered along a board that everything taps
  into. This build has exactly two — +24 V and ground.
- **Star ground:** every ground wire runs *directly* to one point, never
  chained device-to-device. Chained grounds are why zones mismatch.
- **Socketed module:** a board that presses into female pin-headers. A dead
  module becomes a 10-second swap, not a desoldering job.
- **Pigtail & header:** the load's short lead ending in a plug (pigtail); the
  board carries the matching socket (header). Board = header, load = plug.
- **JST-XH vs XT30:** small white plugs for signals and LEDs (3 A) vs chunky
  yellow plugs for power (30 A). Tape and spot ride JST; motors ride XT30.
- **Bulk cap:** a big capacitor that acts like a tiny local battery — it
  feeds the motors' split-second current spikes so the PSU never sees them.
- **Hiccup mode:** how the IRM protects itself. Overloaded, it drops the rail
  and retries. Good protection, confusing symptom: "the whole fixture blinks."
- **Service loop:** slack wire crossing a moving joint in a droop, never taut
  ([Doc 1](01-how-we-got-here.md)'s rule, still in force).
- **Y-splice:** three wire ends twisted, soldered, and covered by one sleeve
  of heat-shrink — how one CAN pair feeds two motors.
- **Standoffs:** the threaded nylon pillars that hold stacked boards apart.

## What you're building

The map below has a side-view panel: **lamp socket → adapter → PSU → three
stacked boards → gimbal head.** The tape ring wraps the body at the middle
board's height. Each board has one job:

- **B1 · POWER** (top, nearest the PSU) — the two trunks, fuse, bench-feed
  XT30, buck, bulk cap, motor XT30s, and the PicoBuck.
- **B2 · DRIVERS** (middle) — both PCA9685s, all four ULNs, and the seven
  zone plugs.
- **B3 · LOGIC** (bottom) — the C6 and the CAN board, so the USB port, WiFi
  antenna, and CAN pair all live at the serviceable end.

The PCAs live *with* the ULNs on purpose: the 21 dim signals never leave
their board, and only about a dozen wires ever cross between boards.

!!! info "The fixture body is its own design track — this chapter builds everything that goes inside it"

    The *body* — the enclosure that holds PSU, stack, tape ring, and gimbal
    together and actually screws in — is being designed separately, as its
    own CAD project, with the real parts in hand for measuring. Nothing
    below waits on it: steps 1–6 build and test the whole stack clamped to
    a bench plate, and step 7 is where electronics and body meet. What the
    body design owes the electronics is exactly this interface list:

    - **PSU mount** — a flat spot for the IRM-90-24ST brick, 109 × 52 ×
      33.5 mm plus finger room for its screw-terminal cover, placed away
      from the LED star's heat.
    - **Cord entry** — a strain-relieved hole where the E26 adapter's two
      leads enter.
    - **Stack mounts** — three M3 standoff points for the 72 mm board
      stack, with a vent path past the boards.
    - **Tape ring at Board 2's height** — the seven zone pigtails are
      short; the tape lives where they reach.
    - **Gimbal clearance** — full pan/tilt travel, plus room for the droopy
      service loops that cross the joints.
    - **Heat path** — the star's heatsink reaches outside air, or the
      step-7 soak proves it doesn't have to.
    - **USB window** — Board 3's USB-C stays reachable, so reflashing never
      means opening the fixture.

    Build the stack first, measure the real thing, then freeze the body —
    the same measure-then-print logic as [Doc 3b](03b-print-the-frame.md)'s
    coupon-first frame.

Three assembly rules:

1. Build each board **flat on the desk**. Stack last.
2. Cut every inter-board wire with slack — **1.5× the gap it crosses**.
3. Route between-board wires past the board edges, never through the middle.

## Soldering these boards (five rules)

Tools out: iron, solder + flux, multimeter, wire strippers, flush cutters,
heat-shrink + a lighter. The rounds have no power rails — just 593 plated
holes — so technique is the whole game:

1. **Sockets: tack ONE pin, look, then finish.** Solder a single corner pin,
   check the strip sits flat, reflow if tilted, then do the rest.
2. **A good joint looks like a tiny volcano.** Heat pad *and* lead ~2
   seconds, feed solder to the joint (not the iron), let it flow, leave.
   Blobby ball = cold joint. Redo it with flux.
3. **Trunks are laid, not drawn.** Strip a length of bus wire, lay it along a
   row of holes, tack it every 4–5 holes. Taps solder straight onto it.
4. **Beep everything before power.** Meter on continuity: every joint you
   made beeps; every *neighboring* pad stays silent. This habit replaces
   most debugging.
5. **Never crimp.** The JST kits come pre-crimped — you solder the bare
   tails. Board side gets the header, load side gets the plug. XT30s: the
   half with recessed metal goes on the live side.

## Bill of Materials — buy this, ~$105 (+ ~$15 of tools)

*"Est." = total for the quantity shown. Prices verified July 2026 —
re-check when ordering.*

| # | Part | Qty | Est. | Where | Notes / traps |
|---|---|---|---|---|---|
| 1 | Round prototyping PCB, 2.84" (72 mm), 593 plated holes, 0.1" pitch | 1 pack of 4 | $15 | [Etsy](https://www.etsy.com/listing/1785807382/vegetable-can-round-prototyping-pcb-w593) | All three get used — B1 power, B2 drivers, B3 logic — plus a spare. No power rails on these boards, which is why the trunk rule exists |
| 2 | Mean Well **IRM-90-24ST** (24 V · 3.75 A · potted · fanless · screw terminals) | 1 | ~$25 | [Bravo Electro](https://www.bravoelectro.com/irm-90-24.html), DigiKey, Mouser | The fixture's PSU. ST variant on purpose: the plain IRM outspans a 72 mm round, so this one mounts to the body — which also keeps the heaviest part off solder joints. Hiccup floor ~103 W clears the ~75 W worst transient |
| 3 | E26 socket-to-wire adapter (660 W rated, 18 AWG leads) | 1 (+1 spare) | $8–12 | Amazon, hardware store | The entire AC feed (~0.6–0.9 A at 120 V). Treat both leads as live; no wall dimmer on that circuit |
| 4 | Female pin-header socket strips, 2.54 mm break-away | 1 kit | $7 | Amazon | Socket every module — C6, both PCAs, CAN board, buck. Dead module = 10-second swap |
| 5 | JST-XH connector kit, **pre-crimped leads** (2/3/4-pin) | 1 kit | $12 | Amazon | 7 tape zones (4-pin each) + the spot (3 ± pairs = six conductors, returns never shared). You solder the tails — never crimp |
| 6 | XT30 connector pairs | 3 pairs | $8 | Amazon | Motor power (one pair per motor) + the bench-feed break. JST-XH is a 3 A part; motor peaks hit 5–8 A |
| 7 | 100 nF ceramic capacitors | ~10 | $6 | Amazon | One at every module's supply pins — long soldered rails need what the breadboard never did |
| 8 | Electrolytic bulk cap, 1000 µF / 35 V, low-ESR | 1 | $3 | Amazon, DigiKey | Rides the motors' millisecond slew peaks. Start at 1000 µF: the IRM publishes no max capacitive load, so if it hiccups at power-on, the cap is too big |
| 9 | Nylon M3 standoff kit | 1 | $9 | Amazon | Stack spacing + a vent path; nylon can't short against pad-side joints |
| 10 | Tinned solid bus wire, 16–18 AWG | 1 roll | $8 | Amazon | Becomes the two trunks |
| 11 | Wire strippers + flush cutters *(if not owned)* | 1 each | ~$15 | Amazon | Never in an earlier BoM — the bench got by, but 100+ soldered joints won't |
| 12 | Silicone stranded wire 22–24 AWG + heat-shrink *(if not owned)* | — | ~$17 | Amazon | The service loops across the pan/tilt joints want the floppiest wire available |

**Carries over from Docs [3](03-build-the-gimbal.md)–[4](04-full-fixture-bench.md) — $0:**
both RMD-L-5005 motors (unit 3 stays the permanent bench spare), the C6
devkit, the SN65HVD230, both PCA9685s (#2 keeps its bridged 0x41 jumper),
4× ULN2803A with their DIP sockets, the PicoBuck, the Cree star + Carclo
optics + heatsink, the Valent X spool (one spool covers even 2× length), the
Pololu buck, the fuse holder + 3 A slow-blow (**step to 4 A if you 2× the
tape** — ~3.1 A sustained nuisance-blows a 3 A), the screw assortment, and
the wire + 10 kΩ resistor stock (three of those 10 ks become the PicoBuck
pulldowns). The bench supply, multimeter, soldering kit, USB-CAN adapter, and
calipers stay on the bench as tools. **Retired:** the breadboards and the
WAGOs — their jobs go to soldered trunks and pluggable pigtails.

## The three small parts, and where every one goes

Three rows of the BoM are easy to buy and then lose track of: the 10 kΩ
resistors, the 100 nF ceramics, and the single big electrolytic. None of them
existed on the breadboard — which is exactly why it can be unclear where they
belong now. They are one idea at three speeds — **hold things steady when
something changes faster than the answer can arrive** — and each has an exact
address:

| Part | How many | Where, exactly | Direction? |
|---|---|---|---|
| 10 kΩ ¼ W resistor | **3** | PicoBuck IN1 / IN2 / IN3, each to the ground trunk — at the driver's pads on B1 (step 5) | no |
| 100 nF ceramic | **5** | one across each socketed module's supply pin and GND: buck, PCA #1, PCA #2, C6 socket, CAN board (steps 2–4) | no |
| 1000 µF / 35 V electrolytic | **1** | across both trunks at the motors' XT30 tap, on B1 (step 6) | **yes — stripe to ground** |

The three 10 kΩ pulldowns: one per PicoBuck input to the ground trunk, soldered on the driver's side of the inter-board wires

The resistors are the spotlight's "dark unless told otherwise" — the
[floats-ON trap](04b-wire-the-spotlight.md#the-driver-demystified) is the why.
The figure's one rule is the where: at the **PicoBuck's** pads, so the promise
holds even with B3 unplugged, swapped, or mid-flash. Step 5's
boot-stays-dark check is these three being proven.

The five 100 nF ceramics: one at each socketed module's supply pins, across all three boards

The ceramics are placement, not mystery: across each socketed module's supply
pin and ground, a centimetre away at most, legs short. Steps 2 and 3 each
place one as they build — this map is the full count of five, including the
two no step spells out (the CAN board and the buck). The PicoBuck sits this
one out: it carries its own capacitors on-board.

The one 1000 µF electrolytic: across both trunks at the motors' power tap, stripe to the ground trunk

The electrolytic is the only one of the three with a direction — **stripe to
ground, always** — and the only one with a single address: across the trunks
at the motors' tap, placed in step 6, spanning the copper step 1 laid down.

## The map — read one lane at a time

Fixture v0 wiring map

One chip runs everything on **seven signal pins**: 2 wires of I²C (21 tape
channels via the PCA9685s), 3 PWM pins (spotlight), 2 CAN pins (both motors,
by address). Power is two trunks on B1. Then build in order — each step is
one bench session, and each has its own diagram below:

| Step | What | Rough time |
|---|---|---|
| 1 | Power backbone | 1–2 h |
| 2 | The brain | 30–45 min |
| 3 | First light (zone 1) | 1–2 h |
| 4 | Scale to 7 zones | an afternoon — it's 28 wires |
| 5 | Spotlight | ~1 h |
| 6 | Gimbal | 1–2 h |
| 7 | Real PSU + verdict | ~1 h + a 30-min soak |

## Step 1 — Power backbone

*Hands-on stage — no agent lane; the level-3 wiring photo check applies.*

Step 1: power backbone

**What's happening:** you're building the two rails everything else drinks
from — and testing them empty.

**Do this:**

1. Set the IRM aside — it mounts to the body at step 7 and stays
   disconnected until then. Everything until then runs from the bench
   supply.
2. Lay the +24 V trunk and the ground trunk along B1 (rule 3).
3. Solder in the fuse holder, then the bench-feed XT30 in the +24 V run.
4. Mount the buck; wire VIN and GND to the trunks.
5. Beep-test every connection (rule 4), then clip the bench supply to the
   bench-feed, current limit at 2 A.

**Done when:** 24 V at the bus, 5 V from the buck, one solid star ground,
nothing warm after five minutes.

**If stuck:** no 24 V = fuse not seated or supply leads reversed. Buck reads
0 V = VIN/GND swapped — it survives that; fix and re-test.

## Step 2 — The brain

Step 2: the brain

**What's happening:** B3 gets its socket, the C6 presses in, and the fixture
gains a computer.

**Do this:**

1. Solder female socket strips for the C6 (rule 1 — tack one pin first).
2. Point the USB-C port at the serviceable end; keep the antenna end away
   from the ground trunk.
3. Run 5 V and GND up from B1. Add a 100 nF cap right at the socket's power
   pins.
4. Press the C6 in.

**Done when:** the C6 boots from stack power alone (USB unplugged) and shows
up in Home Assistant.

**If stuck:** measure 5.0 V *at the C6's socket pins*, not at the buck — a
tilted socket or dry joint drops it on the way.

!!! trap "The dual-power trap"

    First flash happens over USB — and while USB is plugged in, the stack's
    24 V stays OFF. Never feed the C6 from both sides at once. After that
    first flash, every update is wireless.

## Step 3 — First light

*Hands-on stage — no agent lane; the level-3 wiring photo check applies.*

Step 3: zone 1

**What's happening:** one zone travels the whole chain — C6 → PCA #1 → ULN
chip 1 → plug → tape. Get ONE zone perfect before copying it six times.

**Do this:**

1. On B2: solder the PCA #1 socket and the ULN chip-1 DIP socket.
2. Run four wires up from B3: 3V3, GND, SDA (GPIO2), SCL (GPIO3).
3. Wire PCA LED0/1/2 to ULN IN1/2/3; OUT18/17/16 to a 4-pin zone header.
   Counting those pins for the first time? [Doc 4a's ULN pin
   map](04a-wire-the-zones.md#hop-2-the-uln2803-or-eight-switches-in-one-chip)
   numbers every one of them on the real chip, and [its zone-1
   figure](04a-wire-the-zones.md#the-fan-out-which-channel-drives-which-zone)
   photographs this whole step, hub hole to tape pad.
4. Solder the zone-1 pigtail to the tape: +24 V and three channel negatives,
   labeled from the tape's printed pad markings.
5. Run the zone's +24 V wire from the trunk; ULN pin 9 goes straight to star.
6. Beep-test, power up, test from HA.

**Done when:** "Zone 1" sweeps candlelight→daylight from HA, exactly like the
breadboard.

**If stuck:** the ESPHome log's I2C scan says whether 0x40 was found (missing
= SDA/SCL swapped or no VCC). Found but dark = beep the LED0→IN1 and
OUT1→plug runs.

!!! trap "The classic trap, pre-solved"

    PCA9685 VCC gets **3V3 — never 5 V** (at 5 V, I2C fails silently). V+
    stays empty. Drop a 100 nF at VCC while you're there.

## Step 4 — Scale to seven

Step 4: scale to 7 zones

**What's happening:** nothing new — six repeats of step 3, driven by the
channel map on the diagram. Print it; tape it above the bench.

**Do this:**

1. Bridge PCA #2's A0 jumper **before** soldering its socket → it answers at
   0x41 on the same two I2C wires. [Doc 4a photographs those pads open and
   bridged](04a-wire-the-zones.md#the-second-hub-two-boards-the-same-two-wires),
   with the meter reading each one must give — a blob can look bridged and
   touch only one pad.
2. Seat ULN chips 2–4 in their sockets.
3. Work zone by zone from the map: three channels in, three out, one plug.
   Test each zone as its plug lands — unwired zones just sit dark in HA.
4. Label all 28 wires at both ends. Every zone's +24 V comes from the trunk,
   never from a neighboring zone.

**Done when:** seven independent tunable lights, and the "all zones 2200 K @
20%" scene runs — movie mode, now inside a fixture.

**If stuck:** one zone dead? The sockets are your superpower — swap ULN
chip 1 and chip 2. Problem follows the chip → chip; stays with the zone →
wiring. Wrong colors = swapped wires at the plug. Fix wires, not YAML.

## Step 5 — The spotlight

Step 5: spotlight

**What's happening:** three PWM wires dim three constant-current channels,
one per LED die. Each die is individually drivable — one tunable Spotlight or
three separate lights is firmware's choice, not wiring's. Meeting the driver
or the bare star for the first time here? [Doc 4b](04b-wire-the-spotlight.md)
is the bench version of this exact step — the same blocks demystified, the
S-checkpoints, and the which-die-is-which naming ritual whose flags this
step's wiring should already carry.

**Do this:**

1. Mount the star on its heatsink **first** and aim it at a wall — it cooks
   itself bare in under a minute and it is painfully bright.
2. Run GPIO10/11/18 from B3 to the PicoBuck's IN1/2/3 on B1.
3. Solder a 10 kΩ pulldown from each IN to ground — [the small-parts
   figure](#the-three-small-parts-and-where-every-one-goes) draws the exact
   node: wire, resistor, and pin, all meeting at the driver's pad.
4. Wire PicoBuck VIN/GND to the trunks.
5. Wire the three outputs to the three dies: **each output is a ± pair — six
   conductors total — and the returns never share a wire.** Match the printed
   +/− on each die.

**Done when:** every die dims cleanly from HA, and a power-cycle stays dark
through boot.

**If stuck:** one die dark = that pair's polarity, or two wires swapped with
a neighbor's pair. All dark = pulldowns shorted or PWM lines on the wrong
GPIOs.

!!! trap "Why the pulldowns"

    PicoBuck inputs float ON, and the C6's pins float while it boots —
    without pulldowns the spot blasts full-bright at every power-up. The
    boot-stays-dark test in the done-when is these resistors earning their
    keep.

## Step 6 — The gimbal

*Hands-on stage — no agent lane; the level-3 wiring photo check applies.*

Step 6: gimbal

**What's happening:** the motors keep their bench addresses (pan 0x141, tilt
0x142 — set in [Doc 3](03-build-the-gimbal.md) stage 6), so this is wiring,
not configuration.

**Do this:**

1. Wire the SN65 on B3: 3V3, GND to the B3 return, CTX←GPIO6, CRX←GPIO7.
2. Lightly twist the CANH/CANL pair; run it toward the yoke.
3. Y-splice the pair (three ends, one joint, one sleeve of shrink) — short
   stubs to each motor's CANH/CANL.
4. Solder a 120 Ω resistor across CANH–CANL at the **tilt** motor.
5. Motor power: one XT30 pair per motor, 18 AWG straight from the trunks;
   the bulk cap sits at that tap — stripe to the ground trunk, per [the
   small-parts figure](#the-three-small-parts-and-where-every-one-goes).
   Pigtails cross each joint as droopy service loops.
6. Everything OFF: meter across CANH–CANL must read **~60 Ω**. (~120 = a
   terminator missing; open = both.)
7. Raise the bench supply's limit toward **3 A** — two motors plus every LED
   can clip a 2 A limit and sag the rail, which reads as mystery resets.

**Done when:** both motors answer an angle read over the fixture's own
wiring, and the HA pan/tilt sliders move the beam — with all seven zones lit.

**If stuck:** no reply = the [Doc 3](03-build-the-gimbal.md) stage-4 ladder,
in order: 60 Ω check → common ground → CANH/CANL swapped → motor unpowered.
Replies but no motion = you're in Hold/Manual mode, not a wiring problem.

!!! trap "Motors are watched, always"

    First moves happen with your hand near the supply switch and the current
    limit set. A commanded motor twists its own body as hard as its shaft.

## Step 7 — Swap in the real PSU, then the verdict

This is where the fixture body enters: mount the IRM to it, give the E26
adapter's cord a strain-relieved entry, and give the star's heatsink its air
path. (The body arrives from its own design track — the interface list up
top is exactly what this step needs it to provide.)

**Do this:**

1. Disconnect the bench feed.
2. Land the E26 adapter's leads and the trunk wires on the IRM's screw
   terminals — L, N, +Vo, −Vo; there is no earth terminal and none is needed
   (Class II). As built, the ST's output block duplicates its terminals —
   two +Vo screws and two −Vo screws, internally one output — land the
   pigtails one per screw. Fit the terminal cover; screw blocks can't be
   heat-shrunk.
3. Strain-relieve the adapter leads where they enter the body.
4. Screw it into a socket and re-run the short version of everything.

!!! agent-prompt "🤖 Give this to your agent"

    ```text
    You're my bench agent for the Engineered Lighting fixture build
    (chapter: engineering.engineered.lighting/08-build-the-fixture/,
    step 7 — the verdict soak). The hand-soldered fixture is assembled and
    running on its internal IRM-90-24ST; Home Assistant sees all 7 zones,
    the Spotlight, and the pan/tilt controls. Start by proposing a plan
    and wait for my approval before executing anything. Then run the
    verdict with me: walk me through each checklist item in the chapter,
    and for the 30-minute everything-on soak, watch the ESPHome device
    logs the whole time and summarize warnings, resets, and any
    "took a long time" lines; I handle the touch tests and read the
    worst-case current from the meter at the bench-feed point before we
    switch to the IRM.
    SAFETY — non-negotiable: never command motor motion unless I confirm
    I'm watching with a hand near the supply switch. Announce each motion
    command before sending it and wait for my explicit go.
    Done when: every checklist item passes on IRM power.
    Report back: the checklist with pass/fail and evidence per item, and
    the soak-log summary.
    ```

    *[How to run this prompt →](00b-ai-native-workflow.md)*

- [ ] All 7 zones + spotlight + gimbal work on IRM power
- [ ] Power-cycle at the wall switch: the fixture wakes knowing its angles (no homing), and the spot stays dark through boot
- [ ] 30-minute soak, everything on: ULNs warm-not-hot, star heatsink warm, IRM case warm-not-hot, no reboots in the logs
- [ ] Worst-case 24 V current recorded — compare against the ~60 W budget

## What comes after this build — the integrated PCB and the flex circuits

This chapter's stacked protoboards are the last hand-wired version of the fixture. The same architecture
has since been drawn as one eight-layer circuit board: 21 discrete MOSFET channels instead of the ULN
arrays, three independent constant-current spotlight drivers instead of one shared board, and a protected
24 V supply with an electronic breaker, a supervisor and a physical ARM interlock.

[Doc 9](09-understand-the-pcb.md) explains that board part by part, with an interactive viewer of the real
layout. It has been designed and quoted; no board has been built or powered, and nothing in this chapter
depends on it.

The wire this chapter cuts and strips by hand has been drawn too. Three passive flexible circuits carry
the zone feeds up the arm and around the cylinder in place of loose conductors, and
[Doc 10](10-the-flex-circuits.md) covers them. They are quoted and unbuilt as well, so the hand wiring
here remains the only version that exists.

## Risk register

- **Protoboard joints under vibration** — the gimbal shakes its own house.
  Strain-relieve pigtails at each board edge; the socketed modules are the
  serviceable insurance.
- **Heat in an enclosure** — the soak test is the truth. The star's heatsink
  needs an air path through the shell; the IRM sits away from the LED
  thermal mass.
- **Inter-board wiring is where beginner builds die** — hence the board
  allocation that keeps it to ~a dozen wires, the slack rule, and
  build-flat-stack-last.
- **Supply substitutions** — if the IRM-90-24ST drifts out of stock, the
  sizing logic is the spec, not the part number: steady ~25–40 W, transients
  +30–40 W, and the replacement's hiccup floor must clear the sum.

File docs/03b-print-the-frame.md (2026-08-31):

---
title: 3b · Print the Frame
description: "The gimbal's printed frame: four parts that print flat with no supports, no bearings at all, every fit derived from three numbers you measure off your own printer, and a boolean test suite that proves each hole actually exists before you print anything."
---

# Doc 3b · Print the Frame — Four Parts, Three Test Pieces, No Guesswork

**Engineered Lighting prototype series · July 2026**

The frame chapter [Doc 3](03-build-the-gimbal.md) stage 7 points at. Context, fixed: the motors are **RMD-L-5005** (Ø49 × 23.9 mm, 92 g), the spotlight payload is the **DLH-3UP-EH aluminium LED housing** (Ø0.99″ barrel, 1.26″ overall, flush front, hollow ½″-14 NPT rear stub the wires come out of), the printer is a **Bambu Lab X1C**, and the material is **PETG Basic**.

!!! note "This scaffold is reference, not the frame being built"
    The OpenSCAD in this chapter was machine-generated, and it is published as **worked reference** — a documented set of constraints, measured-from-STEP motor geometry, and a boolean test suite showing what a frame has to satisfy. **The frame actually going on this bench is being designed by hand**, with the scaffold as inspiration rather than a source of parts.

    Read the numbers here as *requirements* — the 2.5 mm tapped depth, the 3.0 mm of axial room before the stator, the 0.505 N and 0.0146 N·m the tilt axis carries, the unpublished bearing rating that argument rests on. Those hold for any frame. The specific parts, print orientations and gram counts describe one solution to them.

This is **frame v8**, and it is a ground-up rebuild. Two things drove it.

## What changed, and why it matters

**The motor is now read, not guessed.** Earlier revisions were built on an invented output flange — six holes on a Ø30 circle, an M4 rear mount on Ø43, a 4 mm output boss. None of those exist. The vendor's own STEP file is now in the repo at [`ref/RMD-L-5005-S.STEP`](https://github.com/hooterjackson/engineered-lighting-site/blob/main/ref/RMD-L-5005-S.STEP), parsed by [`ref/step_dump.py`](https://github.com/hooterjackson/engineered-lighting-site/blob/main/ref/step_dump.py), and written up in [`ref/RMD-L-5005-S.md`](https://github.com/hooterjackson/engineered-lighting-site/blob/main/ref/RMD-L-5005-S.md). What it says:

| | |
|---|---|
| Output face | **Flat.** A Ø47 annulus, then a 1 mm 45° chamfer out to Ø49. **There is no boss** — stand-proud is 0.000 mm |
| Output bolts | 4 × M3 on **Ø25**, tapped only **2.500 mm deep**, breaking through into the rotor cavity |
| Stationary housing | begins **3.000 mm** back from the output face |
| Rear mount | 4 × M2.5 on a **20 × 20 mm square** (Ø28.284 at 45°), 10.7 mm deep |
| Through bore | **Ø8.1** ("S" variant) |
| Anything protruding past Ø49 | **Nothing.** Max radius anywhere is exactly R24.5. The connectors are recesses cut *into* the casting |

That 2.5 mm thread depth is the single most constraining number in the design. Every M3 into an output flange is **M3 × 10**, derived from it. The previous revision's assembly drawing called for M3 × 13 and M3 × 14 — both bottom out 2.5–3.5 mm before the head seats, so the joint never clamps and the screw tip ends up inside the motor.

Cross-section of the output flange: the 2.5 mm thread depth, an M3×10 seating and clamping, and an M3×13 bottoming out with its head proud

**The idle side of the tilt axis is gone.** No trunnion, no bearing carrier, no 608, six fewer screws, one fewer yoke arm. The head cantilevers off the tilt motor's own output.

That deletes 62 g from a 177 g machine to carry **0.505 N and 0.0146 N·m** — about 3.5% of the motor's peak torque, with 0.58 N of prying on the output bolts against an M3 proof load near 2000 N. It also removes an *over-constrained* twin-bearing axis: two bearings on one axis need the printed parts to be coaxial with the motor's own bearing, which printed parts cannot guarantee, and which the old design papered over with a build-time "leave three screws loose, swing the head, then tighten" ritual. A misaligned second bearing loads the motor's bearing sideways — it can make worse the thing it is supposed to protect.

!!! warning "One number here is unverified, and it is the important one"

    **The RMD-L manual publishes no bearing load ratings at all.** There is no radial or moment figure for the output. The case for the cantilever is an argument from load magnitude and from the journal diameter — the STEP shows the rotor running in a Ø46.6 bore, and moment capacity scales with that — **not** from a datasheet. The load numbers are echoed on every render so that if the head ever grows, the change is visible instead of silent. If a rating ever surfaces, check it against 0.505 N and 0.0146 N·m.

## The four parts

| Part | What it is | Mass |
|---|---|---|
| `base_plate` | The only part that touches the world. The pan motor's rear bolts up into it, heads counterbored flush; a tongue reaches aft for the C-clamp; a buttressed post hangs down as the pan hard stop | 33.4 g |
| `yoke` | Bridge disc and **one** arm, one piece. Prints standing on its bridge with the arm pointing up — zero supports, and no joint to align because there is no joint | 47.0 g |
| `cradle` | The head's saddle. Bolts flat to the tilt motor's output face and holds the lower half of the housing bore | 23.2 g |
| `cradle_cap` | The other half of the clamp. Four screws pinch the housing between the halves | 21.0 g |
| | **printed machine** | **124.6 g** |

Masses are measured off the exported STLs at PETG density by [`tools/meshcheck.py`](https://github.com/hooterjackson/engineered-lighting-site/blob/main/tools/meshcheck.py), which computes volume and centre of mass twice — once from a hand-rolled divergence-theorem sum, once from `trimesh` — and refuses to report a centre of mass without a stated coordinate frame. v7 was 177.1 g across six parts.

Plus three test pieces that exist to be wrong cheaply, in the order you print them:

**`tol_coupon`** (14.9 g) measures *your printer*. FDM gets holes and shafts wrong in opposite directions — a hole comes out undersize, a post oversize — and every fit here derives from three constants that say by how much. Find which test hole your M3 drops through, which drilled-sideways hole it drops through, and which post measures nominal. Type three numbers into `frame_params.scad` and the whole set resizes itself.

**`fit_coupon`** (11.4 g) checks the *motor*: **two separate tiles**, one per bolt circle. They are separate on purpose — drawn concentrically, the Ø25 and Ø28.284 circles overlap into merged slots, and an M3 and an M2.5 both drop through the same hole, so the coupon proves neither circle.

**`bore_gauge`** (14.2 g) checks the *housing*: a 12 mm slice of the real clamp, both halves lying flat on the bed, the cap half crown-down so its bore prints as a valley exactly as the real cap does.

## The rules the design follows

**Every joint is a bolt you can see.** No tabs, no captive nuts, nothing friction-fit. Printed-to-motor joints use the motor's own threads; printed-to-printed self-taps into printed pilot holes.

**Every fit is derived, never typed.** Three measured constants and the fit functions built on them. Horizontal (bridged) holes get their own class, because a sideways hole prints with a sagging roof and comes out worse than a vertical one.

**The part lands flat on a flat face.** There is no boss to register on, so the four M3 locate it. A plate laid on the output face sits on the Ø47 annulus and has **3.0 mm of axial room at full Ø49** before it touches the stator — which is what would clamp the motor solid.

**Nothing bridges.** The hard stop is a post and a lug that *collide*, not a post in an arc groove: the old groove was 1565 mm² of flat roof with 45 mm unsupported runs printed over a 0.6 mm clearance. There is no groove now, so the whole failure mode is deleted rather than mitigated. The clamp bore is two valleys. Horizontal round holes are hexagons with a vertex up, so the roof is a 60° peak.

!!! note "A trick that only works in one direction"

    The hexagon-vertex-up trick helps a hole whose **axis is horizontal**, where the hexagon's apex becomes the roof. A pocket cut straight down into a face has a flat roof whatever its plan shape. The cap's crown pocket was removed rather than hexagonalised, because the cap prints crown-down and any pocket there is a 32.7 mm bridge directly under the clamp.

**Balance is drawn in, on the axis where it matters.** The tilt axis sits **1.75 mm above** the housing's axis, which puts the measured centre of mass of the whole head — saddle, cap and barrel — on it, leaving 6.9 × 10⁻⁶ N·m of standing torque. Solved from measured geometry by [`tools/solve_balance.py`](https://github.com/hooterjackson/engineered-lighting-site/blob/main/tools/solve_balance.py), in **model** coordinates.

The **pan** axis is deliberately *not* balanced, and the reason is worth stating: the pan axis is vertical and gravity is parallel to it, so a centre-of-mass offset along the arm produces **no torque about the pan axis at all**. The motor holds any heading on zero current whatever that offset is. All it does is load the output bearing with 0.0128 N·m. Nulling it would cost about 7 mm of arm reach, a bigger bridge disc and ~12 g. Reported, not engineered away.

## The parametric scaffold

Four OpenSCAD files. [`cad/frame_params.scad`](cad/frame_params.scad) holds **every number, once**, and every number carries a provenance tag — `[STEP]`, `[MANUAL]`, `[DRAWING]`, `[STD]`, `[CHOICE]`, `[MEASURE]`, `[UNVERIFIED]` — so an invented dimension is visible in the source instead of in a failed build. [`cad/frame.scad`](cad/frame.scad) is nothing but geometry. [`cad/assembly.scad`](cad/assembly.scad) draws the whole machine. [`cad/checks.scad`](cad/checks.scad) is the test suite.

```scad
/* [Motor interface — all [STEP], read out of the vendor's own solid model] */
motor_d          = 49;    // body OD. Also the max radius ANYWHERE: R24.5
motor_len        = 23.9;
out_flat_od      = 47;    // the flat annulus you land on
stator_x         = 3.0;   // ** the stationary housing starts here **
out_bcd          = 25;    // 4 x M3
out_thread_depth = 2.5;   // ** and they break into the rotor cavity **
out_thread_use   = 2.3;   // what we allow ourselves, so there is air under the tip
out_boss_h       = 0;     // there is no boss. 0.000 mm proud.
rear_bcd         = rear_sq * sqrt(2);   // 28.284 — a 20x20 square, at 45 deg

// screw lengths that CANNOT bottom out in the motor, derived not chosen
function out_screw_len(through) = through + out_thread_use;
```

Render or export any part from the CLI. `orient` picks the frame:

```bash
openscad -o tol_coupon.stl -D 'part="tol_coupon"' cad/frame.scad   # print this first
openscad -o yoke.stl       -D 'part="yoke"'       cad/frame.scad   # print orientation
openscad -o yoke_model.stl -D 'part="yoke"' -D 'orient="model"' cad/frame.scad
openscad -o plate.stl      -D 'part="all"'        cad/frame.scad
```

Use `orient="model"` for anything you intend to *measure*. A centre of mass read off a print-orientation export is a rigid transform away from every other number in the project, and reading one as the other is a mistake that has already shipped here once.

## The test suite

`checks.scad` and [`tools/run_checks.py`](https://github.com/hooterjackson/engineered-lighting-site/blob/main/tools/run_checks.py) run **34 checks** of three kinds. Run them after any change:

```bash
python tools/run_checks.py
```

**`hole:` — a hole that must exist.** The probe is the *ideal* hole, intersected with the *finished* part. Empty means the material really was removed. This inversion is the only thing that sees a cut which missed: such a cut removes nothing, changes no mass, and renders as a clean solid. The previous revision's cradle had **no output-flange bolt holes at all** — the cut was a centred cylinder 2.865 mm short of the plate — and nothing but a boolean could see it.

**`clash:` — two things that must not touch**, positioned exactly as assembled: head against both motors and against the yoke at tilt 0 and ±90°, the payload through its sweep, nothing entering the stator zone, the hard-stop post against the bridge and the arm at every heading.

**`bed:` — the exported STL's minimum Z**, measured rather than asserted. The old `p_cradle` put its part 1.740 mm *below* the bed, where a slicer silently clips away the keel's entire first-layer footprint, and `bore_gauge` floated its second half 16 mm in the air.

Both boolean kinds are proven to fail when they should — reintroduce the old centred-cut bug and `hole:yoke_arm_bolts` reports 158.270 mm³; pull `drop` to 12 and `clash:cradle_v_yoke_0` reports 525.1 mm³. A suite that cannot fail is worse than no suite, because it gets believed.

## X1C print settings, per part

| Part | Material | Walls / infill / layer | Orientation | Mass |
|---|---|---|---|---|
| `tol_coupon` | PETG Basic | 3 / 15% / 0.2 mm | flat, as emitted | 14.9 g |
| `fit_coupon` | PETG Basic | 4 / 30% / 0.2 mm | flat, as emitted | 11.4 g |
| `bore_gauge` | PETG Basic | 4 / 40% / 0.2 mm | flat, both halves | 14.2 g |
| `base_plate` | PETG Basic | 4 / 40% gyroid / 0.2 mm | flipped, post UP | 33.4 g |
| `yoke` | PETG-CF if on hand | 5 / 40% gyroid / 0.2 mm | bridge on the bed, arm UP | 47.0 g |
| `cradle` | PETG Basic | 4 / 40% gyroid / 0.2 mm | as emitted, bore a valley | 23.2 g |
| `cradle_cap` | PETG Basic | 4 / 40% / 0.2 mm | crown down, bore a valley | 21.0 g |

Masses are measured off the STLs, not estimated. Print times are not listed because they depend on your profile more than on the geometry — the yoke is the long one at 59.6 mm tall.

`part="all"` lays the whole set flat in **207.5 × 169.7 mm**, which fits a 256 mm X1C bed in **one job**. Those offsets are computed from each part's measured bounding box, not eyeballed. There is not a single support in the set and no overhang past 60°.

## How it all goes together

Open [`cad/assembly.scad`](cad/assembly.scad) and press F5. `view` flips exploded ↔ assembled, `pan` and `tilt` pose it, `show_cap` unchecks to look inside the clamp, and `clip` sections it.

!!! danger "If the version banner prints `undef`, stop"

    `assembly.scad` echoes `cad_version` on load. If that says `undef`, your `frame_params.scad` is not the file these were written against — and OpenSCAD does not fail loudly. It prints `WARNING: Ignoring unknown variable`, collapses the missing names to `undef`, silently **drops the geometry those names positioned**, writes a valid-looking STL and exits 0. A slicer will happily accept it.

    That is the whole explanation for "only some of the parts render". If you have downloaded these files more than once, check what is actually in the folder you opened: a browser saves a second copy as `frame_params_1.scad`, which nothing includes, leaving the *stale* `frame_params.scad` as the one being read. Work in the repo clone, not in a downloads folder.

## Build order

Each step leaves the next step's fasteners reachable — that ordering is a property of the geometry, not a hope.

1. **`tol_coupon` first, before anything else.** Set `hole_comp`, `hole_comp_h` and `shaft_comp` from what it tells you. *Done when three numbers in `frame_params.scad` came off a part you printed.*
2. **Then the other two coupons.** *Done when the output bolts thread one tile, the rear bolts thread the other, and the real housing slides into the bore gauge and locks when you nip its screws.* Fix parameters here; a 20-minute reprint beats a 6-hour one.
3. **Cradle onto the tilt motor**, on the bench, motor loose. Turn the output until two holes sit above the split line, then **two M3 × 10** through the plate. *Done when the cradle is rigid and the motor still turns freely by hand.* Do it now, while a driver reaches straight in.
4. **Tilt motor onto the yoke arm, from outside the arm** — four **M2.5 × 16** through the arm into the rear square. The head is already on and hangs inboard; nothing is trapped. *Done when the head swings freely and falls under its own weight from any angle.*
5. **Yoke onto the pan motor** — four **M3 × 10** up through the bridge.
6. **Base plate down onto the pan motor's rear** — four **M2.5 × 16** through the counterbores. **The connector clocking is decided here**, not earlier: the rear square offers exactly four positions, so turn the motor *now* so its connector faces the cable trough. (The old chapter put this instruction on a step where turning the motor cannot change it, which costs up to three teardowns.) *Done when the plate sits flat and the yoke swings to the stop both ways.*
7. **Wires**, then **housing in, cap on, balance.** Lay the housing into the saddle, slide it until the powered-off head stays where you leave it, *then* pull the four cap screws down.

## Two things worth knowing before you print

**The clamp must never bottom out, and it doesn't.** The barrel is Ø25.15 **± 0.38** — the drawing's own two-place-decimal tolerance, a 0.76 mm spread on the one dimension the clamp depends on. The bore is cut for the *largest* barrel allowed, and the cap's bore sits 0.79 mm above the split line, against a worst case of 0.48 mm of travel needed to reach the *smallest*. So the screws set the grip and any barrel inside tolerance is actually held. Get this backwards and the ears land plastic-on-plastic and clamp air.

There are **9.4 mm of slide** for trim, and it is trim — the balance is drawn in. But note the sleeve length behind it (0.89″ = 22.6 mm) is **unverified**: the drawing carries 0.89, 0.80 and 0.70 and states what none of them measure. Measure yours before relying on the grip length.

**The pan hard stop is mechanical because the whole cable bundle passes through the pan axis.** A post on the base plate and a lug on the bridge's rim collide, giving **329.8°** of travel with the dead wedge aft. Worst case is the motor driving into it at peak torque: 0.42 N·m at a 38.1 mm radius is about 11 N, which puts under 1 MPa in the post's root — roughly 25× margin even across layer lines, and it carries a tapered buttress on top of that because a hard stop is the one feature that gets *hit*.

**Tilt is limited in firmware, not by a stop.** The head's swing radius is 24.3 mm against a 32 mm drop — checked by intersecting the posed head with the yoke as solids at 0 and ±90°, not by eye.

## BoM delta

Against [Doc 3's BoM](03-build-the-gimbal.md#bill-of-materials-buy-this-350405-total): **digital calipers ($10–20)**, because the chapter runs on measurements, and a **small hardware handful (~$10)** — about eight M3 × 10 socket cap screws, eight M2.5 × 16, and four M3 × 25 for the clamp.

**No bearings.** Row 11 of Doc 3 used to list "683 or 608 bearings"; there was never a 683 in the design, and as of v8 there is no bearing at all. No square nuts, no captive hardware, no counterweight.

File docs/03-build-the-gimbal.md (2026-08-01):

---
title: 3 · Build the Gimbal
description: "The 10-stage gimbal bench build: motors answering on CAN by stage 4, a balanced aimed head by stage 8, full BoM and wiring."
---

# Doc 3 · Build the Gimbal — Bench Plan, Step by Step

**Engineered Lighting prototype series · July 2026**
For a first-time gimbal builder with limited electronics experience. Ten stages; each is one bench session with a "you're done when" checkpoint. Motors move on command by stage 4 — no mechanical work needed until stage 7.

## Bill of Materials — buy this, ~$350–405 total

*"Est." = total price for the quantity shown in that row.*

| # | Part | Qty | Est. | Where | Notes / traps |
|---|---|---|---|---|---|
| 1 | **MyActuator RMD-L-5005-100-C** (CAN variant; the -R twin is RS485) | 2 (+1 spare recommended — see note) | $215 for 2 / $322.50 for 3 | [Dings Motion USA](https://www.dingsmotionusa.com/rmd-l-5005), $107.50 ea | The smart pan/tilt actuators — motor, absolute encoder, and tuned controller in one 92 g, Ø49 mm puck; [Doc 2](02-choosing-the-motors.md) is the full story, and its availability addendum covers this exact part swap. Order the **-C (CAN)** variant explicitly. Ask the seller to include mating cables for the **6-pin JST ZH** port (VCC · VCC · GND · GND · CANH · CANL — power is doubled up; it is ZH, *not* the larger XH) — one per motor plus a spare. They ship terminated on both ends, so [Doc 3a](03a-wire-the-bench.md) covers cutting one down into a bench harness. Keep the protocol PDF that ships in the box: it's the authority on byte layouts for your unit's firmware. Why 3: this motor family sells out episodically; the third unit is the permanent bench-dev unit and feeds the future second fixture |
| 2 | ESP32-C6 dev board (ESP32-C6-DevKitC-1) | 1 | $9–15 | Amazon, Adafruit, DigiKey | Same chip as the fixture — everything learned transfers |
| 3 | SN65HVD230 CAN transceiver breakout (Waveshare "CAN Board") | 2 (1+spare) | $8 | Amazon | The ESP32 has the CAN *brain* on-chip but not the line driver — this little board is the voice, converting chip signals to the differential CAN wire pair. 3.3 V logic, breadboard-friendly. Bus termination gets measured and set in stage 3 |
| 4 | 120 Ω resistors, ¼ W | few | $1 | any resistor kit | CAN bus termination |
| 5 | Bench power supply, **≥3 A continuous, adjustable current limit** | 1 | $45–60 | Amazon (any 30 V/5 A unit) | Powers the motors and, later, the whole bench. **Run the motor rail at 24 V** — 12 V is this motor's undervoltage-latch line (stage 1). The adjustable current limit is smoke insurance for a first build, and the 3 A rating covers the motors' real appetite (~1–1.5 A running, 5–8 A instantaneous peaks) |
| 6 | Multimeter | 1 | $20 | Amazon | Non-negotiable — polarity check before every first power-up |
| 7 | Breadboard + jumper wires | 1 kit | $10 | Amazon | Signals only — power never routes through it |
| 8 | USB-C data cable | 1 | — | you own one | Charge-only cables are a classic trap |
| 9 | M2.5 + M3 screw assortment | 1 box | $10 | Amazon | Confirm sizes against the motor drawing ([myactuator.com](https://www.myactuator.com) downloads) |
| 10 | USB-to-CAN adapter ("CANable" or clone) — *optional but recommended* | 1 | $20–25 | Amazon | Lets your laptop eavesdrop on the bus; turns "nothing happens" into readable evidence. It isn't in the stage-3 diagram — [Doc 3a](03a-wire-the-bench.md) shows where it taps in, and [Doc 3c](03c-prove-the-bus.md) turns it into a pre-motor proof of your whole CAN side |
| 11 | PETG filament + access to any FDM 3D printer & slicer | — | $20 | Amazon / local makerspace | For the frame: **four printed parts** (base plate, yoke, cradle, cradle cap) plus three small test coupons — see [Doc 3b](03b-print-the-frame.md). **No bearings.** This row used to read "683 or 608 bearings": there was never a 683 in the design, and as of frame v8 there is no bearing at all — the tilt axis cantilevers off the motor's own output. No printer at home? A library, makerspace, or online print service works — the parts are small |
| 12 | C-clamp or small bench vise | 1 | $10 | hardware store | Stage 4 clamps the bare motor before its first move; stages 7–8 clamp the assembled rig |
| 13 | Payload stand-in: small flashlight or ~100 g weight | 1 | — | — | Real LED head comes from [Doc 4](04-full-fixture-bench.md) |
| 14 | Digital calipers | 1 | $10–20 | Amazon | The frame chapter ([Doc 3b](03b-print-the-frame.md)) runs on measurements — every MEASURE-ME parameter in the scaffold comes from these |

*Family sold out again? [CubeMars GL40 II](https://www.digikey.com/en/products/detail/cubemars/GL-40/16705289) ($134, DigiKey, direct-drive, CAN) is the buy-today alternative at the cost of a protocol port; [M5Stack RollerCAN](https://shop.m5stack.com/products/rollercan-unit-with-bldc-motor-stm32) ($44) is the dev bridge while waiting.*

## Concepts in six terms

- **CAN bus:** a two-wire intercom line. Every device has an address (ours: pan = 0x141, tilt = 0x142 — hex numbers are just house numbers). Messages are always **8 data bytes** — short frames get silently ignored (a documented real-user bug).
- **Transceiver & termination:** the ESP32 has the CAN *brain* on-chip but not the *voice* — the SN65HVD230 chip is the voice. The wire pair needs a 120 Ω resistor at each end (termination) so signals don't echo.
- **Current limit:** a bench supply setting that caps output current. Set low, a wiring mistake fizzles instead of smoking. Our bring-up setting: **2.0 A** at 24 V (enough for one motor to run; still safe). The limit is the insurance — not a low voltage.
- **Common ground:** two power sources (USB-powered ESP32, 24 V motor supply) must share one ground wire, or signals have no reference and *nothing works*. The #1 "why is it dead" cause.
- **Absolute encoder:** the motor knows its angle the instant power arrives — within one revolution (it can't count full turns made while off, so the frame gets hard stops).
- **0xA4:** the workhorse command of this build — "go to angle X, no faster than Y°/s," packed in 8 bytes. The motor does all trajectory math onboard. (A few housekeeping commands appear too: 0x92 read-angle, **0x9A read-status** — volts and error flags, the pre-flight that catches a bad rail — 0x79 set-address, 0x63/0x64 set-zero.)

---

## Stage 1 — Bench setup and the three rules

Set the supply to **24.0 V, current limit 2.0 A** *before* connecting anything (raise toward 3 A in stage 6 for two-motor moves).

**Run the motor rail at 24 V, not 12.** The datasheet range is 12–24 V, but 12 V is this motor's *undervoltage-latch line*, not an operating point: at 12.0 V it acknowledges a move command, refuses to execute it, blinks a latched error, and — this unit's own quirk — takes its CAN interface down until you power-cycle. Bench-verified 2026-07-31, after two hours of chasing wiring that was never wrong. The **current limit**, not the voltage, is your smoke insurance: it caps a wiring fault either way, and reverse polarity kills the drive at any voltage. That's what rule 1 is for.

The rules that prevent 90% of beginner damage: **(1)** multimeter checks polarity before every first power-up; **(2)** wire only with power off; **(3)** one common ground between ESP32 and motor supply.

**Done when:** supply reads 24.0 V / 2.0 A limit and you can explain rule 3.

## Stage 2 — Hello, ESP32 (and exactly how code gets onto the board)

!!! agent-prompt "🤖 Give this to your agent"

    ```text
    You're my bench agent for the Engineered Lighting gimbal build
    (chapter: engineering.engineered.lighting/03-build-the-gimbal/, stage 2).
    An ESP32-C6-DevKitC-1 is plugged into this computer by USB-C. Start by
    proposing a plan and wait for my approval before executing anything.
    Then: install arduino-cli if missing, install the esp32 core (>=3.x),
    detect the board's port, compile and upload the stock Blink example
    (FQBN esp32:esp32:esp32c6), then open a serial monitor at 115200 and
    show me 10 seconds of output. Done when: the LED blinks and you've shown
    me serial output. If upload fails at "Connecting…", tell me to hold the
    BOOT button and retry rather than guessing. Report back: the exact
    commands you ran and the captured output.
    ```

    *[How to run this prompt →](00b-ai-native-workflow.md)*

Every sketch in this doc reaches the board the same way — learn it once here:

<details markdown="1">
<summary>Do it by hand — understand what the agent did</summary>

1. Download **Arduino IDE 2.x** from arduino.cc and install.
2. Open **Boards Manager** (second icon in the left sidebar) → search "esp32" → install **"esp32 by Espressif Systems," version 3.x or newer** (this teaches the IDE about the C6). Takes a few minutes.
3. Plug the dev board in with a **USB-C data cable**.
4. **Tools → Board → esp32 → "ESP32C6 Dev Module"**, then **Tools → Port →** the entry that appeared when you plugged in (Windows: `COM5`-style; Mac: `/dev/cu.usbmodem…`). Not sure which? Unplug, note the list, replug — the new one is yours.
5. Open **File → Examples → 01.Basics → Blink**. Click the **✓ (Verify)** button to compile, then the **→ (Upload)** arrow. The black console below should march through `Writing at 0x… (100%)` and end with `Hard resetting…`.
6. To *see* what the board says: open **Serial Monitor** (magnifying-glass icon, top right), set the dropdown to **115200 baud**, and set the line-ending dropdown beside it to **"New Line"** (the sketches read commands terminated by a newline — with the wrong setting, typed commands sit there doing nothing). This window is your conversation with the microcontroller — every stage-4+ command gets typed here, every reply appears here.
7. From now on: **File → New Sketch → paste the code from this doc → Upload → open Serial Monitor.** That's the whole workflow.

</details>

**Done when:** LED blinks and text appears in Serial Monitor.
**If stuck:** port never appears = charge-only cable (swap it). Upload dies at `Connecting…` = hold the board's **BOOT** button until writing starts. Gibberish in the monitor = baud isn't 115200.

**Have the optional USB-CAN adapter (BoM row 10)?** Before any motor exists, **[Doc 3c · Prove the Bus](03c-prove-the-bus.md)** wires it and the transceiver into a two-node bench bus — no motor, no motor supply — and proves your entire CAN side: driver config, bit timing, transceiver, wiring, and the exact bytes on the wire. Half an hour now, and stage 4's troubleshooting ladder starts with half its rungs pre-checked.

## Stage 3 — Wire the CAN line

*Hands-on stage — no agent lane; the level-3 wiring photo check applies.*

Gimbal CAN wiring diagram

*Color diagram (covers stages 3–6; stage 3 wires Motor A only — Motor B is the dashed box). Plain-text version below for quick bench reference:*

<details markdown="1">
<summary>Plain-text wiring (quick bench reference)</summary>

```
ESP32-C6                SN65HVD230 board          RMD-L-5005 motor
--------                ----------------          ----------------
3V3  ──────────────────  3V3
GND  ──────────────────  GND ───────┬───────────  GND (power minus)
GPIO6 (TX) ────────────  CTX        │
GPIO7 (RX) ────────────  CRX        │
                          CANH ─────┼───────────  CAN H     ← lightly twist
                          CANL ─────┼───────────  CAN L     ← these two
                                    │
Bench supply +24V ──────────────────┼───────────  VCC (power plus)
Bench supply GND ───────────────────┘
```

</details>

Annotations:

- **Why GPIO6/7:** many online examples use GPIO4/5, which are *strapping pins* on the C6 (read by the chip at boot). They usually work; avoiding them removes a category of weird boot behavior for free.
- **Termination check:** with everything unpowered, measure resistance CANH↔CANL. ~120 Ω = one resistor present somewhere; ~60 Ω = two (correct); open = none. Add external 120 Ω resistors until the bus reads ~60 Ω.
- **Motor power never touches the breadboard** (rails are ~1 A). Motor + and − go directly to the supply terminals; only thin signal wires (CAN pair, signal ground) touch the breadboard — with one exception the hard way: the *motor's own* stranded CAN pair belongs in screw terminals, not breadboard clips ([Doc 3a](03a-wire-the-bench.md#signals-the-breadboard-is-the-splitter-with-one-exception)).

The diagram above is a schematic — it shows which signal meets which. The parts in your hands don't have bare wires: the motor ends in a 6-pin **JST ZH** connector, the common ground is a real screw terminal, and the optional USB-CAN sniffer isn't drawn here at all. That layer is **[Doc 3a · Wire It For Real](03a-wire-the-bench.md)** — connector pinout and how to make the harness, what "one ground" looks like with a screwdriver, where wires may split and how, tapping the sniffer onto the bus, and what the little micro-USB board in the motor box is for. Wire there, then come back here and power up.

**Done when:** wired, powered, nothing warm.

## Stage 4 — First contact: read, then move

!!! agent-prompt "🤖 Give this to your agent"

    ```text
    You're my bench agent for the Engineered Lighting gimbal build
    (chapter: engineering.engineered.lighting/03-build-the-gimbal/, stage 4).
    The stage-3 wiring is live on the bench: ESP32-C6 and SN65HVD230 on the
    breadboard, one RMD-L-5005 motor clamped to the bench, supply at 24.0 V
    with the 2.0 A current limit set. Start by proposing a plan and wait for
    my approval before executing anything. Then: compile and upload the
    stage-4 sketch in the chapter (FQBN esp32:esp32:esp32c6, TX=GPIO6,
    RX=GPIO7, CAN at 1 Mbit/s), open serial at 115200 with newline line
    endings, and send r to read the angle (command 0x92) BEFORE any motion —
    any reply at all is the win. Only after I confirm the read: one small
    watched move, a10 (command 0xA4 at 30 deg/s). Traps: CAN frames are
    always 8 data bytes — short frames are silently ignored; the first
    absolute move can sweep up to a half-turn because factory zero is
    arbitrary; if upload dies at "Connecting…", tell me to hold the BOOT
    button and retry rather than guessing; if there is no CAN reply, print
    the twai_get_status_info error counters after a send — climbing counters
    mean wiring, not code.
    SAFETY — non-negotiable: never command motor motion unless I confirm
    I'm watching with a hand near the supply switch. The bench current limit
    stays as set. Announce each motion command before sending it and wait
    for my explicit go.
    Done when: commanded angles work and the power-cycle trick passes.
    Report back: the exact commands you ran and the captured serial output,
    including the raw 0x92 reply frames.
    ```

    *[How to run this prompt →](00b-ai-native-workflow.md)*

**Clamp the motor to the bench first** — a commanded motor twists its own body as hard as its shaft; unclamped motors jump.

Upload:

```cpp
#include "driver/twai.h"

void setup() {
  Serial.begin(115200);
  twai_general_config_t g = TWAI_GENERAL_CONFIG_DEFAULT(
      (gpio_num_t)6, (gpio_num_t)7, TWAI_MODE_NORMAL);   // TX=GPIO6, RX=GPIO7
  twai_timing_config_t t = TWAI_TIMING_CONFIG_1MBITS();  // RMD motors talk at 1 Mbit/s
  twai_filter_config_t f = TWAI_FILTER_CONFIG_ACCEPT_ALL();
  twai_driver_install(&g, &t, &f);
  twai_start();
  Serial.println("CAN up. r = read angle, a<deg> = move (a45), z = go to 0");
}

void send8(uint32_t id, uint8_t d0,uint8_t d1,uint8_t d2,uint8_t d3,
                        uint8_t d4,uint8_t d5,uint8_t d6,uint8_t d7) {
  twai_message_t m = {}; m.identifier = id; m.data_length_code = 8;   // ALWAYS 8 bytes
  uint8_t d[8] = {d0,d1,d2,d3,d4,d5,d6,d7}; memcpy(m.data, d, 8);
  twai_transmit(&m, pdMS_TO_TICKS(100));
}

// 0xA4 = "go to <deg> absolute, max <dps> deg/sec". deg → hundredths, little-endian.
void moveTo(float deg, uint16_t dps) {
  int32_t p = (int32_t)(deg * 100.0f);
  send8(0x141, 0xA4, 0x00, dps & 0xFF, dps >> 8,
        p & 0xFF, (p >> 8) & 0xFF, (p >> 16) & 0xFF, (p >> 24) & 0xFF);
}

void loop() {
  if (Serial.available()) {
    String c = Serial.readStringUntil('\n'); c.trim();
    if (c == "r")      send8(0x141, 0x92,0,0,0,0,0,0,0);   // read angle
    else if (c == "s") send8(0x141, 0x9A,0,0,0,0,0,0,0);   // status: volts + errors
    else if (c == "z") moveTo(0, 30);
    else if (c.startsWith("a")) moveTo(c.substring(1).toFloat(), 30);
  }
  twai_message_t rx;
  if (twai_receive(&rx, 0) == ESP_OK) {
    Serial.printf("reply id=0x%03X data=", (unsigned)rx.identifier);
    for (int i = 0; i < 8; i++) Serial.printf("%02X ", rx.data[i]);
    Serial.println();
  }
}
```

The session: type `r` — **any reply is the win** (proves wiring, transceiver, bitrate, motor). Then type `s` before you move anything: the reply's bytes 4–5 are the supply voltage *as the motor measures it* (0.1 V per count, so `F0 00` = 24.0 V) and bytes 6–7 are its error flags. **You want 24-ish volts and `00 00`.** Thirty seconds here buys you the whole failure tree below. Then `a10` — the motor turns to absolute 10° and holds (it resists a gentle hand). Heads-up on the very first move: the factory zero is wherever assembly left it, so the first absolute command may sweep up to a half-turn — calm at the 30°/s limit, but that's why the motor is clamped. Play with `a45`, `a-30`, `z`.

**The no-homing party trick:** move to `a45`, kill motor power, nudge the shaft (less than a full turn), power on, type `r` — it still knows its angle. That's the product's silent-wake feature. Fine print: single-turn encoder, so the frame gets hard stops making a full off-power revolution impossible.

**Done when:** commanded angles work and the power-cycle trick passes.
**If stuck (no reply):** first check the software non-bug — Serial Monitor line-ending set to "New Line" (stage 2, step 6)? Then hardware, in order: CANH/CANL swapped → missing common ground → motor unpowered → termination. The driver fails *silently* on a broken bus; print `twai_get_status_info` error counters after a send (climbing counters = wiring, not code). This is where the $20 USB-CAN dongle earns its keep. One more, learned the hard way: **thin stranded wire in a breadboard clip is not a connection** — see [Doc 3a](03a-wire-the-bench.md#where-wires-may-split-and-how).

**If it acks but won't move (and the LED starts slow-blinking):** the motor is *fine* and your wiring is fine — it has latched a **Level-2 error** and is refusing motion. Read `s` (0x9A): if the voltage is near 12 V, that is the diagnosis — this 24 V-nominal motor latches undervoltage the instant its power stage tries to energize (stage 1). Raise the rail to 24 V and power-cycle. Two follow-ons worth knowing: the fault also takes this unit's **CAN interface down** — reads that worked a second ago go silent, and the error counters stay clean because your side is blameless — and a **power cycle is the verified recovery** (the protocol's 0x76 system-reset may also work; untested here). Blinking LED = latched error, solid = healthy: that little light is the fastest instrument on the bench.

## Stage 5 — Characterize (the measurements everything depends on)

!!! agent-prompt "🤖 Give this to your agent"

    ```text
    You're my bench agent for the Engineered Lighting gimbal build
    (chapter: engineering.engineered.lighting/03-build-the-gimbal/, stage 5).
    The stage-4 rig is live: one clamped motor answering 0x92/0xA4 over CAN,
    and I'm standing by with a phone dB app and the supply ammeter — I call
    out every meter reading, you log it. Start by proposing a plan and wait
    for my approval before executing anything. Then drive the stage's
    measurement sweeps using the stage-4 sketch in the chapter: noise at
    hold and during moves at 10 / 30 / 60 / 90 deg/s (phone at 30 cm, same
    app throughout so stage-10 numbers compare); hold current unloaded and
    then with ~100 g hung 4 cm off-axis; warmth after 30 minutes holding;
    and the resolution steps a10.00, a10.50, a10.05 with a flashlight taped
    on while I watch the wall. Pause after each condition, prompt me for the
    reading, and build the noise/current table as we go. The fast rows
    matter most: follow-me needs 54–80 deg/s on close passes, so they decide
    whether tracking stays silent or gets speed-capped.
    SAFETY — non-negotiable: never command motor motion unless I confirm
    I'm watching with a hand near the supply switch. The bench current limit
    stays as set. Announce each motion command before sending it and wait
    for my explicit go.
    Done when: the numbers are written down.
    Report back: the completed noise/current table and the serial log of
    every command you sent.
    ```

    *[How to run this prompt →](00b-ai-native-workflow.md)*

- **Noise** (phone dB app — pick one and stick with it so stage-10 numbers compare, e.g. NIOSH SLM on iOS or Sound Meter on Android; 30 cm distance): at hold, and during moves at **10 / 30 / 60 / 90 °/s**. Quiet room ≈ 30–40 dB. Two verdicts ride on this: whine *at hold* (the sealed loop can't be retuned — this is the RMD bet's one risk), and the speed where motion becomes audible — **follow-me needs 54–80°/s on close passes** ([Doc 5](05-teach-it-to-aim.md)), so the fast rows decide whether tracking stays silent or gets speed-capped.
- **Hold current** (supply ammeter): unloaded, then with ~100 g hung 4 cm off-axis — previews why the balanced head matters.
- **Warmth** after 30 min holding: warm fine; too-hot-to-touch is thermal-budget data.
- **Resolution feel:** step `a10.00 → a10.50 → a10.05` with a flashlight taped on; watch the wall (0.05° ≈ 2 mm at 2.4 m).

**Done when:** the numbers are written down.

## Stage 6 — Second motor, one bus

!!! agent-prompt "🤖 Give this to your agent"

    ```text
    You're my bench agent for the Engineered Lighting gimbal build
    (chapter: engineering.engineered.lighting/03-build-the-gimbal/, stage 6).
    Motor B is on the bench at the factory address, connected ALONE on the
    CAN pair; motor A is disconnected for the re-address step. Start by
    proposing a plan and wait for my approval before executing anything.
    Then: change motor B's ID to 2 with command 0x79 per the manual's "CAN
    ID setting" section — send that write exactly once, never in a loop
    (it's a persistent flash write, so wear is real, and it only takes
    effect after a reboot), have me power-cycle the motor, and verify it
    now answers at 0x142. Next I'll T-tap both motors off one CANH/CANL
    trunk (the L series has one port, so this is a tap, not a chain) and
    raise the supply current limit toward 3 A; then
    extend the stage-4 sketch in the chapter with a b<deg> command for
    motor 0x142 and a combined p<deg> t<deg> command that sends the two
    0xA4 frames back-to-back (~0.1 ms apart — simultaneous for a
    spotlight).
    SAFETY — non-negotiable: never command motor motion unless I confirm
    I'm watching with a hand near the supply switch. The bench current limit
    stays as set. Announce each motion command before sending it and wait
    for my explicit go.
    Done when: combined pan+tilt commands move both motors; each still
    answers alone.
    Report back: the sketch diff and serial captures showing replies from
    both 0x141 and 0x142.
    ```

    *[How to run this prompt →](00b-ai-native-workflow.md)*

Motors ship with the same address, so: connect motor B **alone**, change its ID to 2 (command 0x79 per the manual's "CAN ID setting" section, or MyActuator's PC tool), power-cycle, verify it answers at 0x142. Then T-tap both motors off one CANH/CANL trunk — the L series has a single port, so this is a tap, not a chain ([Doc 3a](03a-wire-the-bench.md#one-port-no-daisy-chain)) — raise the current limit toward 3 A, extend the sketch with `b<deg>` and a combined command (two frames back-to-back ≈ 0.1 ms apart — simultaneous for a spotlight).

> From here on, some stages describe *what* to add rather than printing every line — deliberately: this is where the **AI-as-lab-partner workflow (below)** takes over. "Extend the stage-4 sketch with a `b<deg>` command for motor 0x142 and a combined `p<deg> t<deg>` command" is a one-prompt job.

**Done when:** combined pan+tilt commands move both motors; each still answers alone.

## Stage 7 — Print the frame, balance the head

*Hands-on stage — no agent lane; the level-3 wiring photo check applies.*

A printed frame turns two motors into an aimed head. **[Doc 3b](03b-print-the-frame.md) publishes a worked reference design** — four parts, three test pieces, motor geometry measured out of the vendor STEP, and a boolean suite that proves each hole exists before you print. The frame on this bench is being drawn by hand with that as inspiration; treat 3b's numbers as the *constraints any frame must satisfy* rather than a parts list to copy. The chapter is **[Doc 3b · Print the Frame](03b-print-the-frame.md)**. Print there, then come back here to wire and balance.

Wire routing: motor pigtails (power + CAN) cross each joint as a loose **service loop** — droopy, never taut across full travel.

**Balancing (the important 20 minutes):** power OFF, the head should stay wherever you pose it. If it flops, slacken the cradle cap and slide the housing until it stays — frame v8 balances by moving mass onto the axis, not by adding a counterweight. Balanced head = near-zero hold current = silent and cool. Verify: hold current at 0°/45°/90° tilt barely differs from the unloaded stage-5 reading.

**Done when:** the powered-off head stays posed anywhere; powered moves are smooth, no cable snags.

## Stage 8 — Aim at the room

!!! agent-prompt "🤖 Give this to your agent"

    ```text
    You're my bench agent for the Engineered Lighting gimbal build
    (chapter: engineering.engineered.lighting/03-build-the-gimbal/, stage 8).
    The balanced rig from stage 7 is clamped at a measured height h above
    the desk, with a desk-corner origin and taped target marks measured in
    meters. Start by proposing a plan and wait for my approval before
    executing anything. Then: extend the stage-6 sketch in the chapter with
    a goto x y serial command implementing the stage's math — pan =
    atan2(y_t - y_f, x_t - x_f), tilt = atan(horizontal_distance / h) —
    using the h and fixture position (x_f, y_f) I give you. Upload, then
    walk the beam between the taped marks one goto at a time, logging
    commanded target vs. where the beam actually lands so we can see the
    systematic error (mount lean, zero offsets) — in the product that
    becomes a one-time install calibration.
    SAFETY — non-negotiable: never command motor motion unless I confirm
    I'm watching with a hand near the supply switch. The bench current limit
    stays as set. Announce each motion command before sending it and wait
    for my explicit go.
    Done when: goto 0.5 0.3 lands within a few cm, repeatably.
    Report back: the sketch diff, the goto commands you sent, and the
    logged table of commanded vs. actual landings with the systematic
    offset noted.
    ```

    *[How to run this prompt →](00b-ai-native-workflow.md)*

Clamp the rig at height *h* above the desk. Pick an origin (a desk corner), measure in meters. For a target at (x_t, y_t) with the fixture at (x_f, y_f): `pan = atan2(y_t − y_f, x_t − x_f)`, `tilt = atan(horizontal_distance / h)`. Add a `goto x y` serial command implementing that; walk the beam between taped marks; note the systematic error (mount lean, zero offsets) — in the product this becomes a one-time install calibration.

**Done when:** `goto 0.5 0.3` lands within a few cm, repeatably.

## Stage 9 — Hand the keys to the network

!!! agent-prompt "🤖 Give this to your agent"

    ```text
    You're my bench agent for the Engineered Lighting gimbal build
    (chapter: engineering.engineered.lighting/03-build-the-gimbal/, stage 9).
    The aimed rig from stage 8 is on the bench, and a Home Assistant
    machine running the Mosquitto broker add-on is on the LAN — I'll give
    you its IP and the WiFi details. Start by proposing a plan and wait for
    my approval before executing anything. Then: add WiFi + MQTT to the
    stage-8 sketch in the chapter using the PubSubClient and ArduinoJson
    libraries. Subscribe to spotlight/target and parse the Doc 6 envelope
    {"v":1,"ts":1784150000000,"pan":32.5,"tilt":-14,"rate":10} — v and ts
    are the contract's mandatory envelope fields — into the two CAN frames,
    and publish read-back angles every few seconds. Then test end to end:
    publish a target from this laptop (mosquitto_pub or MQTT Explorer),
    watch the read-back topic confirm the move, and do the final check with
    the USB cable unplugged.
    SAFETY — non-negotiable: never command motor motion unless I confirm
    I'm watching with a hand near the supply switch. The bench current limit
    stays as set. Announce each motion command before sending it and wait
    for my explicit go.
    Done when: an MQTT publish from your laptop aims the beam, no USB
    attached.
    Report back: the sketch diff and a mosquitto_sub -t 'spotlight/#' -v
    capture showing the published target and the read-back angles that
    followed.
    ```

    *[How to run this prompt →](00b-ai-native-workflow.md)*

Add WiFi + MQTT: install the **PubSubClient** and **ArduinoJson** libraries (Sketch → Include Library → Manage Libraries, search by name). The broker is the **Mosquitto add-on in Home Assistant** ([Doc 4's prerequisites box](04-full-fixture-bench.md#prerequisites)) — point the sketch at your HA machine's IP. Behavior: subscribe to **`spotlight/target`**, parse `{"v":1,"ts":1784150000000,"pan":32.5,"tilt":-14,"rate":10}` (`v`/`ts` are the contract's mandatory envelope fields — [Doc 6](06-message-contract.md)) → two CAN frames; publish read-back angles every few seconds. Note: this MQTT lane is the *bench* interface — production replaces it with a direct native-API action ([Doc 6 §1](06-message-contract.md#1-spotlighttarget-aim-commands-gpu-box-fixture-stream-15-hz)). (Another one-prompt AI-partner job: "add WiFi+MQTT to this sketch per this paragraph.") Test from MQTT Explorer or a Home Assistant automation.

**Done when:** an MQTT publish from your laptop aims the beam, no USB attached.

## Stage 10 — Verdict checklist

- [ ] Hold noise, balanced head, several angles — indistinguishable from the room (<~35 dB)
- [ ] Sweep noise at 10–90°/s (the speed-vs-silence decision)
- [ ] Repeatability: same `goto` mark 20×, scatter ≤ 1 cm at 1 m (≈0.5°)
- [ ] Power-loss recovery: correct angle knowledge, zero homing motion
- [ ] 4-hour hold: current, temperature, no intermittent whine
- [ ] 50 full-travel sweeps: service loops intact
- [ ] Total power draw at 24 V — record it for the fixture power budget (external design doc: the fixture brief's ~60 W mode-based table)

**Pass** → the architecture graduates to the fixture's lower-module PCB (C6 TWAI + $2 transceiver, actuators as-is). (The hand-built stop before any PCB — this gimbal plus [Doc 4](04-full-fixture-bench.md)'s bench, soldered into a real fixture — is **[Doc 8](08-build-the-fixture.md)**.) **Whine or heat at hold** → re-balance harder, then fall back to the DIY FOC path ([Doc 2](02-choosing-the-motors.md), "The DIY path and its documented pain") where you own the loop.

## AI as your lab partner

The Serial Monitor output, compiler errors, and CAN frames in this build are all text — which makes every debugging step here something an AI can read, reason about, and often fix. Four levels, in order of setup effort:

**Level 0 — paste the evidence (zero setup).** When something misbehaves, paste into Claude: the *entire* sketch, the *entire* Serial Monitor output (not excerpts — the boring lines are often the clue), and one sentence on what you expected. Compiler errors especially: ESP32 toolchain errors are verbose and AI-friendly. This alone resolves most beginner walls.

**Level 1 — let the agent drive the board (Claude Code + arduino-cli).** Arduino has a command-line twin, `arduino-cli`, which means a coding agent with shell access can run the whole loop itself:

```bash
arduino-cli compile --fqbn esp32:esp32:esp32c6 gimbal_sketch/ --upload -p /dev/cu.usbmodem101
arduino-cli monitor -p /dev/cu.usbmodem101 -c baudrate=115200
```

Run Claude Code in the folder holding your sketch (keep it in git so edits are reviewable) and ask things like: *"Upload this, send `r` over serial, capture 30 seconds of output, and tell me why the reply frames don't decode as angles."* (For scripted send-and-capture the agent will typically write itself a five-line pyserial helper rather than use the interactive monitor — let it.) The agent edits, recompiles, re-uploads, and re-reads output in a loop — the same iteration you'd do by hand, minus the hand. Give it these docs as context so it knows the pins, addresses, and protocol.

**Level 2 — let the agent see the bus and the telemetry.** The optional USB-CAN dongle (BoM #10) turns raw bus traffic into text an agent can decode. On a Mac bench (yours), that's a small **python-can** script with the dongle in `slcan` mode streaming every frame as text; on a Linux box it's one command (`candump can0`). Either way, Claude can diff what's on the wire against the RMD protocol PDF — far better than a human squinting at hex. Once stage 9 adds MQTT, `mosquitto_sub -t 'spotlight/#' -v` gives an agent live telemetry to watch while it commands test moves and checks the reported angles match.

**Level 3 — let it see the bench.** Photograph the breadboard and ask Claude to check the wiring against this doc's stage-3 diagram before first power-up. Cheap, catches swapped CANH/CANL and missing grounds surprisingly well.

**One hard rule:** the agent never commands motion unattended. Current limit stays set, your hand stays near the supply switch, and any agent-driven test that moves the motor happens while you watch. Agents are excellent at reading; keep the physical-safety authority human.

## Reference card

| Thing | Value |
|---|---|
| CAN bitrate / frame size | 1 Mbit/s · always 8 data bytes |
| Motor addresses | pan 0x141 · tilt 0x142 (set via cmd 0x79) |
| Move command | 0xA4: `[A4 00 spdLo spdHi pos0..pos3]`, pos = deg×100, int32 little-endian |
| Read angle / set zero | 0x92 · 0x63/0x64 (zero write needs reboot; do once, never in a loop — flash wear) |
| Health / recovery | **0x9A** — bytes 4–5 = supply volts (0.1 V/count), 6–7 = error flags (0x0004 = low voltage). 0x76 = system reset (untested; power cycle is the verified recovery) |
| LED codes | solid = running normally · **slow flash = latched Level-2 error** (undervoltage, over-temp…) · fast flash = Level-1, needs restart |
| Pins | TX=GPIO6→CTX, RX=GPIO7←CRX (GPIO4/5 avoided: strapping pins) |
| Supply | **24 V** @ 2.0 A limit (→~3 A two-motor). 12 V is the undervoltage-latch line, not an operating point. Motor power direct to PSU, never via breadboard |
| Golden rules | multimeter first · wire cold · one ground · twist CANH/CANL · balanced head = silent head |

## Risk register

- **Hold whine.** A balanced head should hold silently; audible whine at hold means current is fighting gravity — rebalance (stage 7's housing slide) before blaming the motor. Stage 5's hold-noise row is the baseline; stage 10 re-checks it at several angles.
- **Undervoltage latch, and the mute that follows.** At 12 V this 24 V-nominal motor acks moves, refuses them, slow-blinks, and drops off CAN until a power cycle — the failure looks exactly like bad wiring and is not (bench-verified 2026-07-31). Run the rail at 24 V, and read 0x9A before the first move of any session.
- **Protocol drift.** Byte layouts vary across RMD firmware revisions — the protocol PDF that ships in the box is the authority for *your* unit, over anything online (including this doc's frame examples). When replies don't decode, diff against the PDF first.
- **Single-turn absolute encoder.** The motor knows its angle within one revolution but can't count full turns made while powered off — the frame's hard stops (stage 7) are what make power-loss recovery unambiguous. Don't delete them to save print time.
- **Supply volatility.** This motor family sells out episodically at retail (the 4005 did exactly that in July 2026 — see Doc 2's addendum). The third-unit spare in the BoM is the insurance; the alternates line under the BoM is the fallback path.
- **Speed vs. silence.** The 54–80 °/s band that follow-me needs (stage 5) may not be silent on your unit. If it isn't, the perception layer speed-caps close passes — losing some tracking snappiness — rather than accepting audible sweeps. Decide with stage-10 data, not hope.

## Further reading

- [MyActuator RMD-L-5005 downloads](https://www.myactuator.com) — the STEP files (stage 7 frame design) and the protocol PDF that is the authority on your unit's byte layouts.
- [isaac879's Pan-Tilt-Mount](https://github.com/isaac879/Pan-Tilt-Mount) — printable pan/tilt geometry worth studying before designing the yoke.
- [Visaging ESP32-Gimbal](https://github.com/Visaging/ESP32-Gimbal) — an ESP32-class gimbal build; different goals (stabilization), same mechanical vocabulary.

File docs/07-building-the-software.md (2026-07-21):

---
title: 7 · Building the Software
description: "The software: pinned stack, repo layout, hardware-free testing, deployment, and the firmware growth path."
---

# Doc 7 · Building the Software — Stack, Repos, Testing, Deployment

**Engineered Lighting prototype series · July 2026**
How the code actually gets built: the services on the GPU box, the fixture firmware's growth path, and — the part that usually gets skipped — how to test all of it without standing in front of a camera holding a book. Every package and pattern here was verified against official docs/source in July 2026.

## Nothing to buy

Everything here is open source. The costs are attention and discipline.

## Concepts (plain English)

- **Restreamer:** a small server (go2rtc / mediamtx) that connects to each camera *once* and re-serves the stream locally to any number of consumers — isolating flaky camera connections from your code, and doubling as the replay rig for testing.
- **uv workspace:** one Python repo containing several packages (tracker, resolver, context bridge) sharing a single lockfile — the current standard toolchain (uv won; even OpenAI acquired its maker in 2026 and kept it open source).
- **Golden test:** record a real session's tracks once, replay them into the resolver in CI forever — asserting the same inputs still produce the same aim outputs.
- **ESPHome `host` platform:** compiles your fixture config into a *native program* on your dev machine — real `api:` server, template outputs standing in for hardware — so the resolver can be integration-tested against a simulated fixture with zero hardware. ESPHome's own CI tests itself exactly this way.
- **External component:** the sanctioned way ESPHome lambdas grow up — a small Python+C++ package (`components/fixture_control/`) that YAML then imports. The old "custom component" hack is dead (removed 2025); this is its successor.
- **GPL boundary:** ESPHome's C++ core is GPLv3 (its Python tooling is MIT). Any C++ you compile into the firmware binary joins a GPLv3 combined work — fine for prototypes and open products, a real decision point for the commercial fixture (§6).

## 1. The services on the GPU box (what runs, in what process)

```
cameras ──► go2rtc/mediamtx restream (one local RTSP per room)
              │
              ├─► TRACKER  (one process per room)          ─┐
              │    ultralytics.track(stream=True,           │ MQTT (QoS 0)
              │    persist=True, tracker=bytetrack)         │ el/<room>/tracks @15Hz
              │    feet→ground-plane → One-Euro/prediction ─┘ + perception/status
              │
              ├─► CONTEXT BRIDGE (one process, GPU)
              │    event-triggered clips → V-JEPA → el/<room>/context (retained)
              │
              └─► Frigate (recording/review only — off the control path)

RESOLVER (one asyncio process, uvloop)
  subscribes tracks+context (aiomqtt) · watches HA state_changed w/ contexts (hass-client)
  computes per-fixture pan/tilt · safety cones · assignment
  → bench: publishes spotlight/target (MQTT)
  → production: calls fixture_aim() directly (aioesphomeapi + ReconnectLogic, one client per fixture)
```

Why process-per-camera (Frigate's pattern, not Ultralytics' threading example): isolation — one room's camera flaking can't stall the others, and each tracker restarts independently. The RTX 6000 has orders-of-magnitude more throughput than a home needs, so batching efficiency (DeepStream's win) buys nothing here.

**The stack, pinned (July 2026, all verified):**

| Role | Package | Version note |
|---|---|---|
| Detection + tracking | `ultralytics` | ≥8.4.63 (YOLO26 + current trackers; ByteTrack = cheapest for static cameras) |
| Camera restream + replay | go2rtc v1.9.14 or mediamtx v1.19.2 | either; go2rtc already ships inside Frigate |
| Async MQTT | `aiomqtt` | **==2.5.1** (3.0.0a1 exists — alpha, skip) |
| ESPHome native API client | `aioesphomeapi` | ≥45.6.0; use `ReconnectLogic` (backoff + instant mDNS reconnect) |
| HA observation | `hass-client` | ==1.2.3 — asyncio WebSocket client, production-proven by Music Assistant; subscribes `state_changed` *with context data* (the override detector's food) |
| Event loop | `uvloop` | latest |
| Config models | `pydantic` 2.x | per-room YAML loaded with `yaml.safe_load` + `model_validate` (pydantic-settings' YAML source can't do nested sections — known open issue — so keep it for process env only) |
| Env/build | `uv` | workspace mode |
| GPU containers | `nvidia-container-toolkit` + compose `deploy.resources.reservations.devices` | Frigate's own install pattern |

**Three ingest rules that prevent the classic seconds-of-lag bug:** always read through the local restream (never direct-to-camera); set `OPENCV_FFMPEG_CAPTURE_OPTIONS="rtsp_transport;tcp|fflags;nobuffer|flags;low_delay"` before opening; and know that Ultralytics' `stream=True` loader already keeps only the newest frame internally (verified in its source) — the env var still matters because it opens plain `cv2.VideoCapture` underneath.

**Calling the fixture (production lane), the whole pattern:**

```python
api = aioesphomeapi.APIClient("fixture-1.local", 6053, None, noise_psk=PSK)  # encryption mandatory ≥2026.1
entities, services = await api.list_entities_services()
aim = next(s for s in services if s.name == "fixture_aim")
await api.execute_service(aim, {"pan": 32.5, "tilt": -14.0})   # typed floats, fire-and-forget, ~12 Hz
```

## 2. Repo layout (one monorepo, uv workspace)

```
engineered-lighting/
  services/
    tracker/          # per-camera process; pyproject each; uv workspace members
    resolver/
    context_bridge/
  libs/roommodel/     # shared pydantic models: tracks, context, targets (Doc 6 schemas as code)
  firmware/           # the ESPHome tree (see §4)
  config/rooms/*.yaml # one file per room: camera URL+pose, fixture poses+calibration, labeled surfaces
  deploy/docker-compose.yaml
  tests/
    golden_tracks/    # recorded jsonl track sessions
    clips/            # short mp4s for RTSP replay
```

`libs/roommodel` is where [Doc 6](06-message-contract.md) stops being prose: every schema becomes a pydantic model, and both publisher and subscriber import the same class — the contract enforced by the type checker instead of by discipline.

## 3. Testing without a living room (the part that makes AI-partner development fly)

- **Replay cameras:** mediamtx loops an mp4 as a real RTSP source (`runOnInit: ffmpeg -re -stream_loop -1 …`, or its native `alwaysAvailableFile:`); go2rtc's `exec:` source does the same. Record 2 minutes of walking through the room once; the tracker develops against it forever.
- **Golden tracks:** capture `(ts, id, x, y, vx, vy)` jsonl from a session; replay at wall-clock pace into the resolver in CI; assert pan/tilt outputs within tolerance. Geometry (homography, aim inverse, cone checks) gets plain `pytest` + `numpy.testing.assert_allclose`.
- **Simulated fixture — the big one:** an `esphome` config with `host:` + `api:` + template outputs compiles to a native binary exposing the *real* API server. The resolver's integration test spins it up as a subprocess, connects with real `aioesphomeapi`, calls `fixture_aim`, and asserts state — the identical pattern ESPHome's own `tests/integration/` uses in its CI. End-to-end resolver→firmware-logic testing, zero hardware, runs in GitHub Actions. (Host caveats: no MQTT component, no real GPIO — template stand-ins only, which is exactly what you want.)
- **Why this matters doubly:** every one of these loops is text-in/text-out, which means Claude Code can run the full suite, read failures, and iterate — the Docs [3](03-build-the-gimbal.md)/[4](04-full-fixture-bench.md) lab-partner workflow extended to the whole system.

## 4. Firmware engineering (bench → fleet → product)

```
firmware/
  components/fixture_control/    # the graduated C++ external component (RMD CAN driver,
                                 #   aim gate, watchdog) — starts as type: local
  packages/
    base-fixture.yaml            # PCA9685, canbus, api+actions, ota, logger — shared
    network.yaml · mqtt.yaml     # mqtt: discovery: false
  devices/<room>/fixture-NN.yaml # thin per-fixture file: substitutions + package includes
  secrets.yaml                   # gitignored; remote packages can't use !secret — pass via substitutions
  tests/host/                    # the simulated-fixture configs from §3
  .github/workflows/             # esphome config validate + esphome/build-action@v8 matrix
```

- **When lambdas graduate:** the [Doc 4](04-full-fixture-bench.md) lambdas are right for the bench. The moment the CAN logic grows (telemetry parsing, two-stage failsafe, calibration hooks), it becomes `components/fixture_control/` — the official skeleton is ~3 files (`__init__.py` schema + `.h/.cpp`), and `mrk-its/esphome-canopen` is the structural reference for a component that rides the built-in `canbus:`. **Verified negative: no RMD/CyberGear/ODrive ESPHome component exists anywhere — ours is greenfield**, and a candidate for open-sourcing (community moat, exactly the Made-for-ESPHome ethos).
- **Fleet pattern:** one base package + thin per-device files that set only substitutions (the jesserockz/ESPHome-maintainer pattern); Jinja expressions in substitutions (2025.7+) derive per-fixture CAN IDs and offsets. Fleet updates: `esphome update-all`, Device Builder's bulk actions (2026.6+), or HA `update.*` entities.
- **Performance discipline on the single core (all source-verified):** the loop-block warning threshold is now **50 ms** (raised from the oft-cited 30 ms in mid-2025); CAN RX drains its whole queue inline per tick — fine at our tens of frames/sec, **but keep `logger:` at INFO once telemetry flows** (per-frame DEBUG logging is the documented crash cause on busy CAN nodes); structure the CAN component event-style (`disable_loop()` when idle) rather than polling.
- **The product licensing decision (flag for counsel, not resolvable here):** ESPHome's C++ core is **GPLv3** — a commercial fixture shipping ESPHome-based firmware ships a GPLv3 combined work: source availability plus the anti-lock-down clause (users must be able to install modified firmware) — in direct tension with signed OTA. Real precedents exist for embracing it (Apollo Automation and Athom ship ESPHome commercially; the free "Made for ESPHome" program formalizes it) — but every confirmed precedent is open-hardware prosumer gear, not a mass-market appliance. The alternatives: keep ESPHome for prototypes/dev-kits and write ESP-IDF firmware for the sealed product (the aim/CAN/failsafe logic ports cleanly — it's the smallest part of what ESPHome provides), or lean into openness as strategy (it *is* on-brand for the HA-first launch audience). Decide before the commercial firmware effort starts, not after.

## 5. Deployment (one GPU box, boring on purpose)

Single `docker-compose.yaml`: restreamer, tracker-per-room, context-bridge, resolver, Frigate — GPU services declare `deploy.resources.reservations.devices` (NVIDIA runtime via `nvidia-ctk runtime configure`). One systemd unit runs `docker compose up -d` at boot; compose owns restarts. Mosquitto and HA stay where they are (the HA box); everything meets on the LAN per [Doc 5](05-teach-it-to-aim.md)'s VLAN plan.

## 6. Build order (the first two weeks of software)

!!! agent-prompt "🤖 Give this to your agent"

    ```text
    You're my bench agent for the Engineered Lighting software build
    (chapter: engineering.engineered.lighting/07-building-the-software/,
    build-order step 1 — repo bootstrap). Everything in this step is
    hardware-free and runs on the GPU box; no camera, no fixture.

    Start by proposing a plan and wait for my approval before executing
    anything.

    Task: bootstrap the monorepo exactly per the chapter's repo layout: a
    uv workspace with services/tracker, services/resolver, and
    services/context_bridge (a pyproject each, one shared lockfile);
    libs/roommodel encoding the Doc 6 message schemas as pydantic 2.x
    models so publisher and subscriber import the same class;
    config/rooms/ with per-room YAML loaded via yaml.safe_load +
    model_validate; deploy/docker-compose.yaml; the firmware/ tree
    skeleton; and tests/golden_tracks + tests/clips directories. Pin the
    chapter's stack exactly — ultralytics >=8.4.63, aiomqtt ==2.5.1,
    aioesphomeapi >=45.6.0, hass-client ==1.2.3, uvloop, pydantic 2.x —
    but re-verify every pin at build time per the chapter's version-drift
    rule and flag anything that moved.

    Done when: uv sync succeeds across the whole workspace and the
    service skeletons, roommodel schemas, and compose file are committed.

    Report back: the repo tree, the uv sync output, any pin that drifted
    from the chapter's table, and the diff.
    ```

    *[How to run this prompt →](00b-ai-native-workflow.md)*

1. Repo bootstrap: uv workspace, `libs/roommodel` encoding [Doc 6](06-message-contract.md)'s schemas, empty service skeletons, compose file. *(An afternoon, mostly Claude Code.)*

!!! agent-prompt "🤖 Give this to your agent"

    ```text
    You're my bench agent for the Engineered Lighting software build
    (chapter: engineering.engineered.lighting/07-building-the-software/,
    build-order step 2 — replay rig before real cameras). The repo from
    step 1 exists; a 2-minute recorded clip of someone walking the room
    stands in for a live camera, so this step touches no hardware.

    Start by proposing a plan and wait for my approval before executing
    anything.

    Task: build the replay rig and the tracker MVP against it. Configure
    mediamtx to loop the mp4 as a real local RTSP source (runOnInit with
    ffmpeg -re -stream_loop -1, or its native alwaysAvailableFile). Then
    the tracker (one process per room): ultralytics track with
    stream=True, persist=True, tracker=bytetrack; feet to ground-plane
    position; One-Euro smoothing plus prediction; publish
    el/<room>/tracks at 15 Hz (MQTT QoS 0) plus perception/status. Obey
    the chapter's three ingest rules: always read through the local
    restream; set OPENCV_FFMPEG_CAPTURE_OPTIONS to
    "rtsp_transport;tcp|fflags;nobuffer|flags;low_delay" before opening;
    and rely on stream=True keeping only the newest frame. Use the
    chapter's pinned versions, re-verifying pins at build time per the
    version-drift rule.

    Done when: mosquitto_sub shows sane 15 Hz tracks from a looped clip.

    Report back: a mosquitto_sub capture of el/<room>/tracks with the
    measured publish rate, per-frame processing latency on the GPU box,
    and the diff.
    ```

    *[How to run this prompt →](00b-ai-native-workflow.md)*

2. Replay rig before real cameras: mediamtx looping a recorded clip → tracker MVP against it → tracks on MQTT. **Done when** `mosquitto_sub` shows sane 15 Hz tracks from a looped clip.

!!! agent-prompt "🤖 Give this to your agent"

    ```text
    You're my bench agent for the Engineered Lighting software build
    (chapter: engineering.engineered.lighting/07-building-the-software/,
    build-order step 3 — resolver MVP). The step-2 tracker is publishing
    el/<room>/tracks at 15 Hz from the looped clip; still no hardware
    anywhere.

    Start by proposing a plan and wait for my approval before executing
    anything.

    Task: build the resolver as one asyncio process on uvloop: subscribe
    tracks and context with aiomqtt (==2.5.1); compute per-fixture
    pan/tilt with the aim math driven by the fixture poses and
    calibration in config/rooms/; include the safety-cone checks and
    assignment; publish bench targets on spotlight/target using the Doc 6
    envelope fields. Testing: capture a golden-track session as (ts, id,
    x, y, vx, vy) jsonl into tests/golden_tracks/, replay it at
    wall-clock pace into the resolver in CI, and assert the pan/tilt
    outputs within tolerance; cover the pure geometry (homography, aim
    inverse, cone checks) with plain pytest +
    numpy.testing.assert_allclose. Follow the chapter's pins,
    re-verifying at build time per the version-drift rule.

    Done when: golden-track replay produces expected angles in pytest.

    Report back: the pytest output including the golden-track tolerances,
    a sample of the published spotlight/target messages, and the diff.
    ```

    *[How to run this prompt →](00b-ai-native-workflow.md)*

3. Resolver MVP: consume tracks, aim math from `config/rooms/`, publish bench targets. **Done when** golden-track replay produces expected angles in pytest.

!!! agent-prompt "🤖 Give this to your agent"

    ```text
    You're my bench agent for the Engineered Lighting software build
    (chapter: engineering.engineered.lighting/07-building-the-software/,
    build-order step 4 — the simulated fixture). The step-3 resolver
    passes its golden-track tests; this step stays entirely hardware-free
    — the fixture is a compiled host-platform binary.

    Start by proposing a plan and wait for my approval before executing
    anything.

    Task: create an esphome config in firmware/tests/host/ using the host
    platform with an api server and template outputs standing in for
    hardware, exposing the fixture_aim action. Then the integration test:
    spin the compiled binary up as a subprocess, connect with real
    aioesphomeapi (>=45.6.0, ReconnectLogic, noise encryption — mandatory
    since 2026.1), call fixture_aim with typed floats, and assert the
    resulting state — the same pattern ESPHome's own tests/integration/
    uses in its CI. Remember the host caveats: no MQTT component, no real
    GPIO — template stand-ins only, which is exactly what we want. Wire
    it into GitHub Actions alongside esphome config validate.

    Done when: the whole loop passes with no hardware attached.

    Report back: the integration-test pytest output, the CI run result,
    and the diff.
    ```

    *[How to run this prompt →](00b-ai-native-workflow.md)*

4. Simulated fixture: host-platform config + `fixture_aim` action; resolver integration test green in CI. **Done when** the whole loop passes with no hardware attached.

!!! agent-prompt "🤖 Give this to your agent"

    ```text
    You're my bench agent for the Engineered Lighting software build
    (chapter: engineering.engineered.lighting/07-building-the-software/,
    build-order step 5 — point it at reality). Steps 1-4 proved every
    component against the replay rig and the simulated fixture; this step
    prepares the swap to the real camera and the Doc 4 bench rig but
    stays hardware-free itself — anything that actually moves the fixture
    belongs to the Doc 5 Phase 0 session and its own prompt.

    Start by proposing a plan and wait for my approval before executing
    anything.

    Task: make the swap a pure configuration change. Point the restreamer
    at the real camera's RTSP URL (still reading only through the local
    restream, per the ingest rules), update config/rooms/ with the real
    camera pose and fixture pose, and switch the resolver's output to the
    bench lane — spotlight/target over MQTT, which the Doc 4 ESPHome node
    forwards to CAN. Verify the perception side only: the tracker
    consuming the live stream, sane 15 Hz tracks on el/<room>/tracks, the
    resolver publishing plausible angles — with the fixture's supply left
    off. Do not command or enable any fixture motion in this session.

    Done when: the tracker runs against the live camera and the resolver
    publishes plausible bench targets, with every component already
    tested before hardware enters — the remaining unknowns are physics,
    not code.

    Report back: a mosquitto_sub capture of el/<room>/tracks and of
    spotlight/target from the live stream, the measured track rate, and
    the config diff.
    ```

    *[How to run this prompt →](00b-ai-native-workflow.md)*

5. Point it at reality: swap the looped clip for the real camera, the simulated fixture for the bench rig — this is [Doc 5 Phase 0](05-teach-it-to-aim.md#phase-0-the-lamp-follows-me-a-weekend-needs-only-the-doc-34-rig-any-rtsp-camera), arrived at with every component already tested. The remaining unknowns are physics, not code.

!!! agent-prompt "🤖 Give this to your agent"

    ```text
    You're my bench agent for the Engineered Lighting software build
    (chapter: engineering.engineered.lighting/07-building-the-software/,
    build-order step 6 — graduating the firmware and override detection).
    The full loop from steps 1-5 runs; the Doc 4 CAN lambdas have
    outgrown a screen. This step is code and host-platform tests only —
    no flashing, no hardware.

    Start by proposing a plan and wait for my approval before executing
    anything.

    Task: graduate the CAN lambdas into the external component
    firmware/components/fixture_control/ (starts as type: local) — the
    official ~3-file skeleton (__init__.py schema plus .h/.cpp), riding
    the built-in canbus, with mrk-its/esphome-canopen as the structural
    reference; ours is greenfield, since no RMD ESPHome component exists
    anywhere. Respect the chapter's single-core discipline: event-style
    structure with disable_loop() when idle, logger at INFO once
    telemetry flows, and the 50 ms loop-block threshold. Separately, wire
    hass-client (==1.2.3) into the resolver to subscribe state_changed
    with context data — the override detector's food — so the coordinator
    notices manual overrides. Validate with esphome config validate and
    the step-4 host-platform integration tests.

    Done when: the fixture_control component compiles, config validate
    and the host-platform integration tests pass, and a replayed
    state_changed event with context data is logged as a detected manual
    override.

    Report back: the esphome config validate output, the host-platform
    test results, the override-detection log line, and the diff.
    ```

    *[How to run this prompt →](00b-ai-native-workflow.md)*

6. Graduate the CAN lambdas into `fixture_control` when they exceed a screen; wire `hass-client` override detection when the coordinator starts making choices worth overriding.

## Risk register

- **`hass-client` is maintained by one adjacent project** (Music Assistant) — solid today; the fallback is ~200 lines of raw websocket client, so the exposure is bounded.
- **YOLO26/Ultralytics licensing is AGPL** for the library — fine for personal/prototype use; a commercial product needs an Ultralytics license or a differently-licensed detector. Same decision-gate timing as the ESPHome GPL question; bundle them for counsel.
- **No public benchmark exists** for this exact GPU on these exact loads (unchanged from [Doc 5](05-teach-it-to-aim.md)) — step 2's replay rig is also the benchmark harness.
- **Version drift:** everything above was verified July 2026; re-verify pins at build time (the pre-purchase-recheck rule from the hardware BoMs, applied to software).

## Further reading

Ultralytics track mode — [docs.ultralytics.com/modes/track](https://docs.ultralytics.com/modes/track) · aioesphomeapi — [github.com/esphome/aioesphomeapi](https://github.com/esphome/aioesphomeapi) · ESPHome host platform — [esphome.io/components/host](https://esphome.io/components/host) · ESPHome external components — [esphome.io/components/external_components](https://esphome.io/components/external_components) + [developers.esphome.io/architecture/components](https://developers.esphome.io/architecture/components) · esphome-canopen (structural reference) — [github.com/mrk-its/esphome-canopen](https://github.com/mrk-its/esphome-canopen) · build-action — [github.com/esphome/build-action](https://github.com/esphome/build-action) · packages/fleet pattern — [esphome.io/components/packages](https://esphome.io/components/packages) + [github.com/jesserockz/esphome-configs](https://github.com/jesserockz/esphome-configs) · mediamtx config (replay) — [mediamtx.org/docs](https://mediamtx.org/docs) · Frigate architecture (process-per-camera precedent) — [docs.frigate.video](https://docs.frigate.video) · hass-client — [github.com/music-assistant/python-hass-client](https://github.com/music-assistant/python-hass-client) · aiomqtt — [pypi.org/project/aiomqtt](https://pypi.org/project/aiomqtt) · uv workspaces — [docs.astral.sh/uv](https://docs.astral.sh/uv) · ESPHome LICENSE (GPL boundary) — [github.com/esphome/esphome/blob/dev/LICENSE](https://github.com/esphome/esphome/blob/dev/LICENSE) · Made for ESPHome — [esphome.io/guides/made_for_esphome](https://esphome.io/guides/made_for_esphome)

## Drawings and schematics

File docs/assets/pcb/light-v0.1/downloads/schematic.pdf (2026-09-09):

1 | 2 | 3 | 4 | 5 | 6 | 7 | 8

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
### F Date: 2026-09-08

KiCad E.D.A. 10.0.3 | Id: 1/20
Size: A3 | Rev: LIGHT v0.2 candidate

# Title: Integrated lighting controller

### File: engineered-lighting-rev-a.kicad_sch

### Sheet: /

## Engineered Lighting

### ENGINEERING DRAFT - see release status before fabrication

pwm

File: pwm.kicad_sch

central_led_interface

File: central_led_interface.kicad_sch

power_1

File: power_1.kicad_sch

power_2

File: power_2.kicad_sch

zone_2

File: zone_2.kicad_sch

spot_1

File: spot_1.kicad_sch

can

File: can.kicad_sch monitor_expansion

File: monitor_expansion.kicad_sch

zone_6

File: zone_6.kicad_sch

controller File: controller.kicad_sch

zone_4

File: zone_4.kicad_sch

test File: test.kicad_sch

spot_2

File: spot_2.kicad_sch

power_sequence

File: power_sequence.kicad_sch

zone_1

File: zone_1.kicad_sch

zone_5

File: zone_5.kicad_sch

usb

File: usb.kicad_sch

zone_3

File: zone_3.kicad_sch

zone_7

File: zone_7.kicad_sch

F1 / Q500 / U12
Fuse, reverse block, eFuse

V24_BUS + bulk U501 pulse clamp

### 76.2 mm envelope / eight copper layers / factory SMD assembly

Functional energy and data map - electrical nets are on the child sheets. | F4-F10 -> 7 ambient zones 21 MOSFET sinks / common +24 V U14 -> V24_SPOT -> 3 x AL8860 U500 clamp / three paired LED outputs

F2/F3 -> 2 CAN motors

J16 external brake / bus port F11 -> U10 5 V -> U11 3.3 V ESP32-C6 / PCA9685 / CAN logic U13 switches gate pullup bias

J1 / external 24 V USB: interface bias only DATA / CONTROL GPIO2/3 I2C -> U2 0x40 / U3 0x41 -> 21 PWM sinks GPIO10/11/18 -> 3 spotlight PWM; GPIO6/7 -> CAN

GPIO0 AND ARM AND READY -> SAFE
TMP112 0x48; J18 GPIO19-23 / 3V3
Strap probes: GPIO4/5/15; USB12/13; UART16/17

Prototype only: source/current/thermal/RF and motor-energy tests remain pending. Open ARM = lighting inhibited. Motor stopping/holding is a separate function.

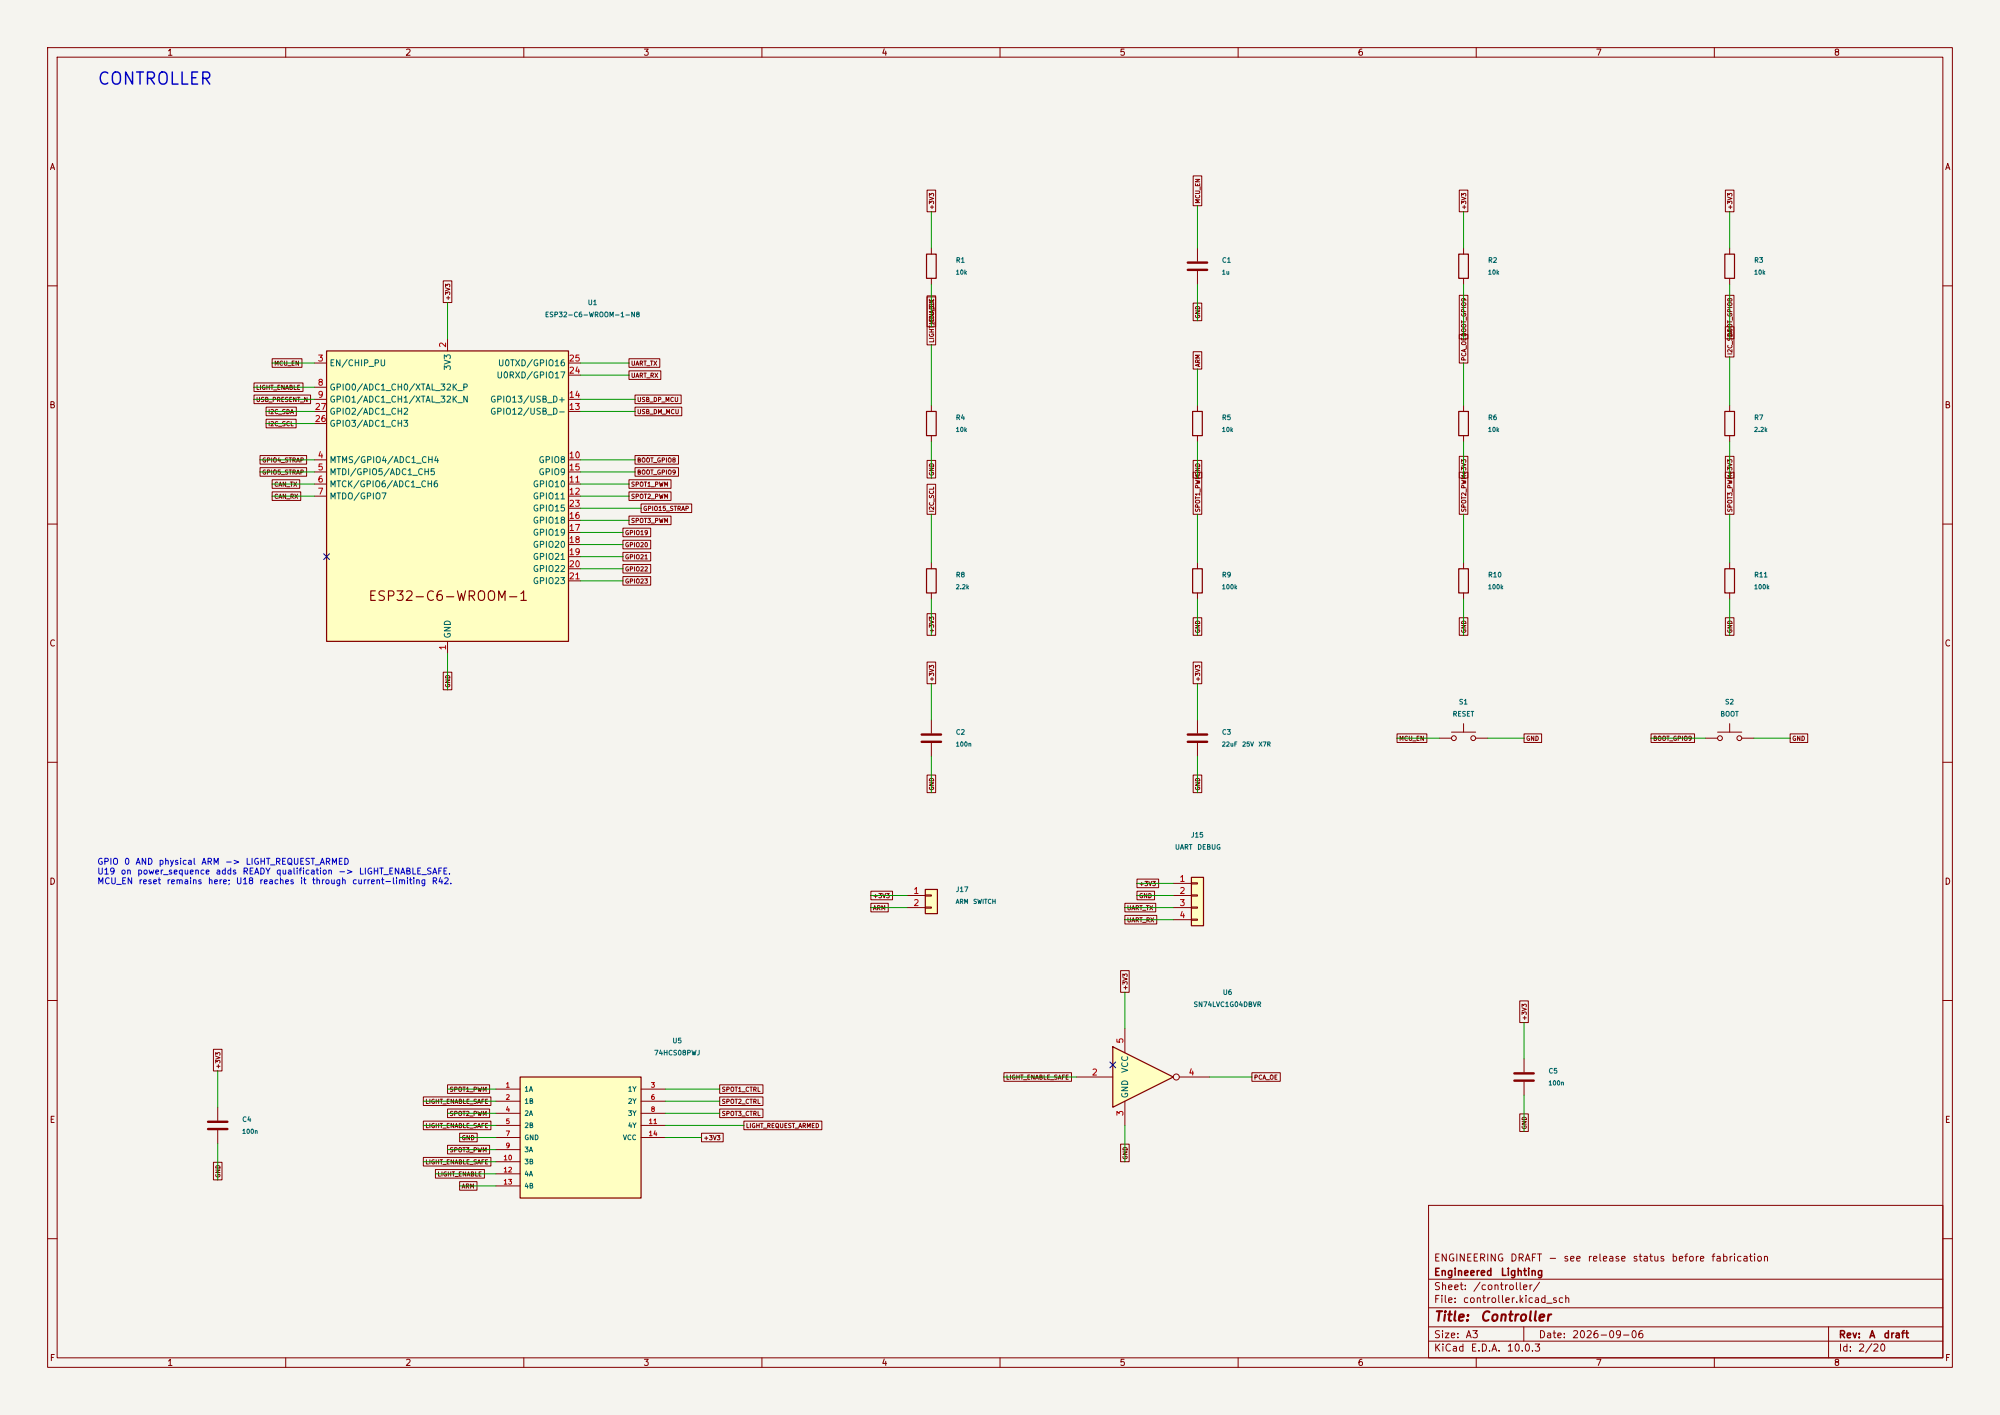
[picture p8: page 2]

GPIO 0 AND physical ARM -> LIGHT_REQUEST_ARMED U19 on power_sequence adds READY qualification -> LIGHT_ENABLE_SAFE. MCU_EN reset remains here; U18 reaches it through current-limiting R42.

ENGINEERING DRAFT - see release status before fabrication
Engineered Lighting
Sheet: /controller/
File: controller.kicad_sch
Title: Controller

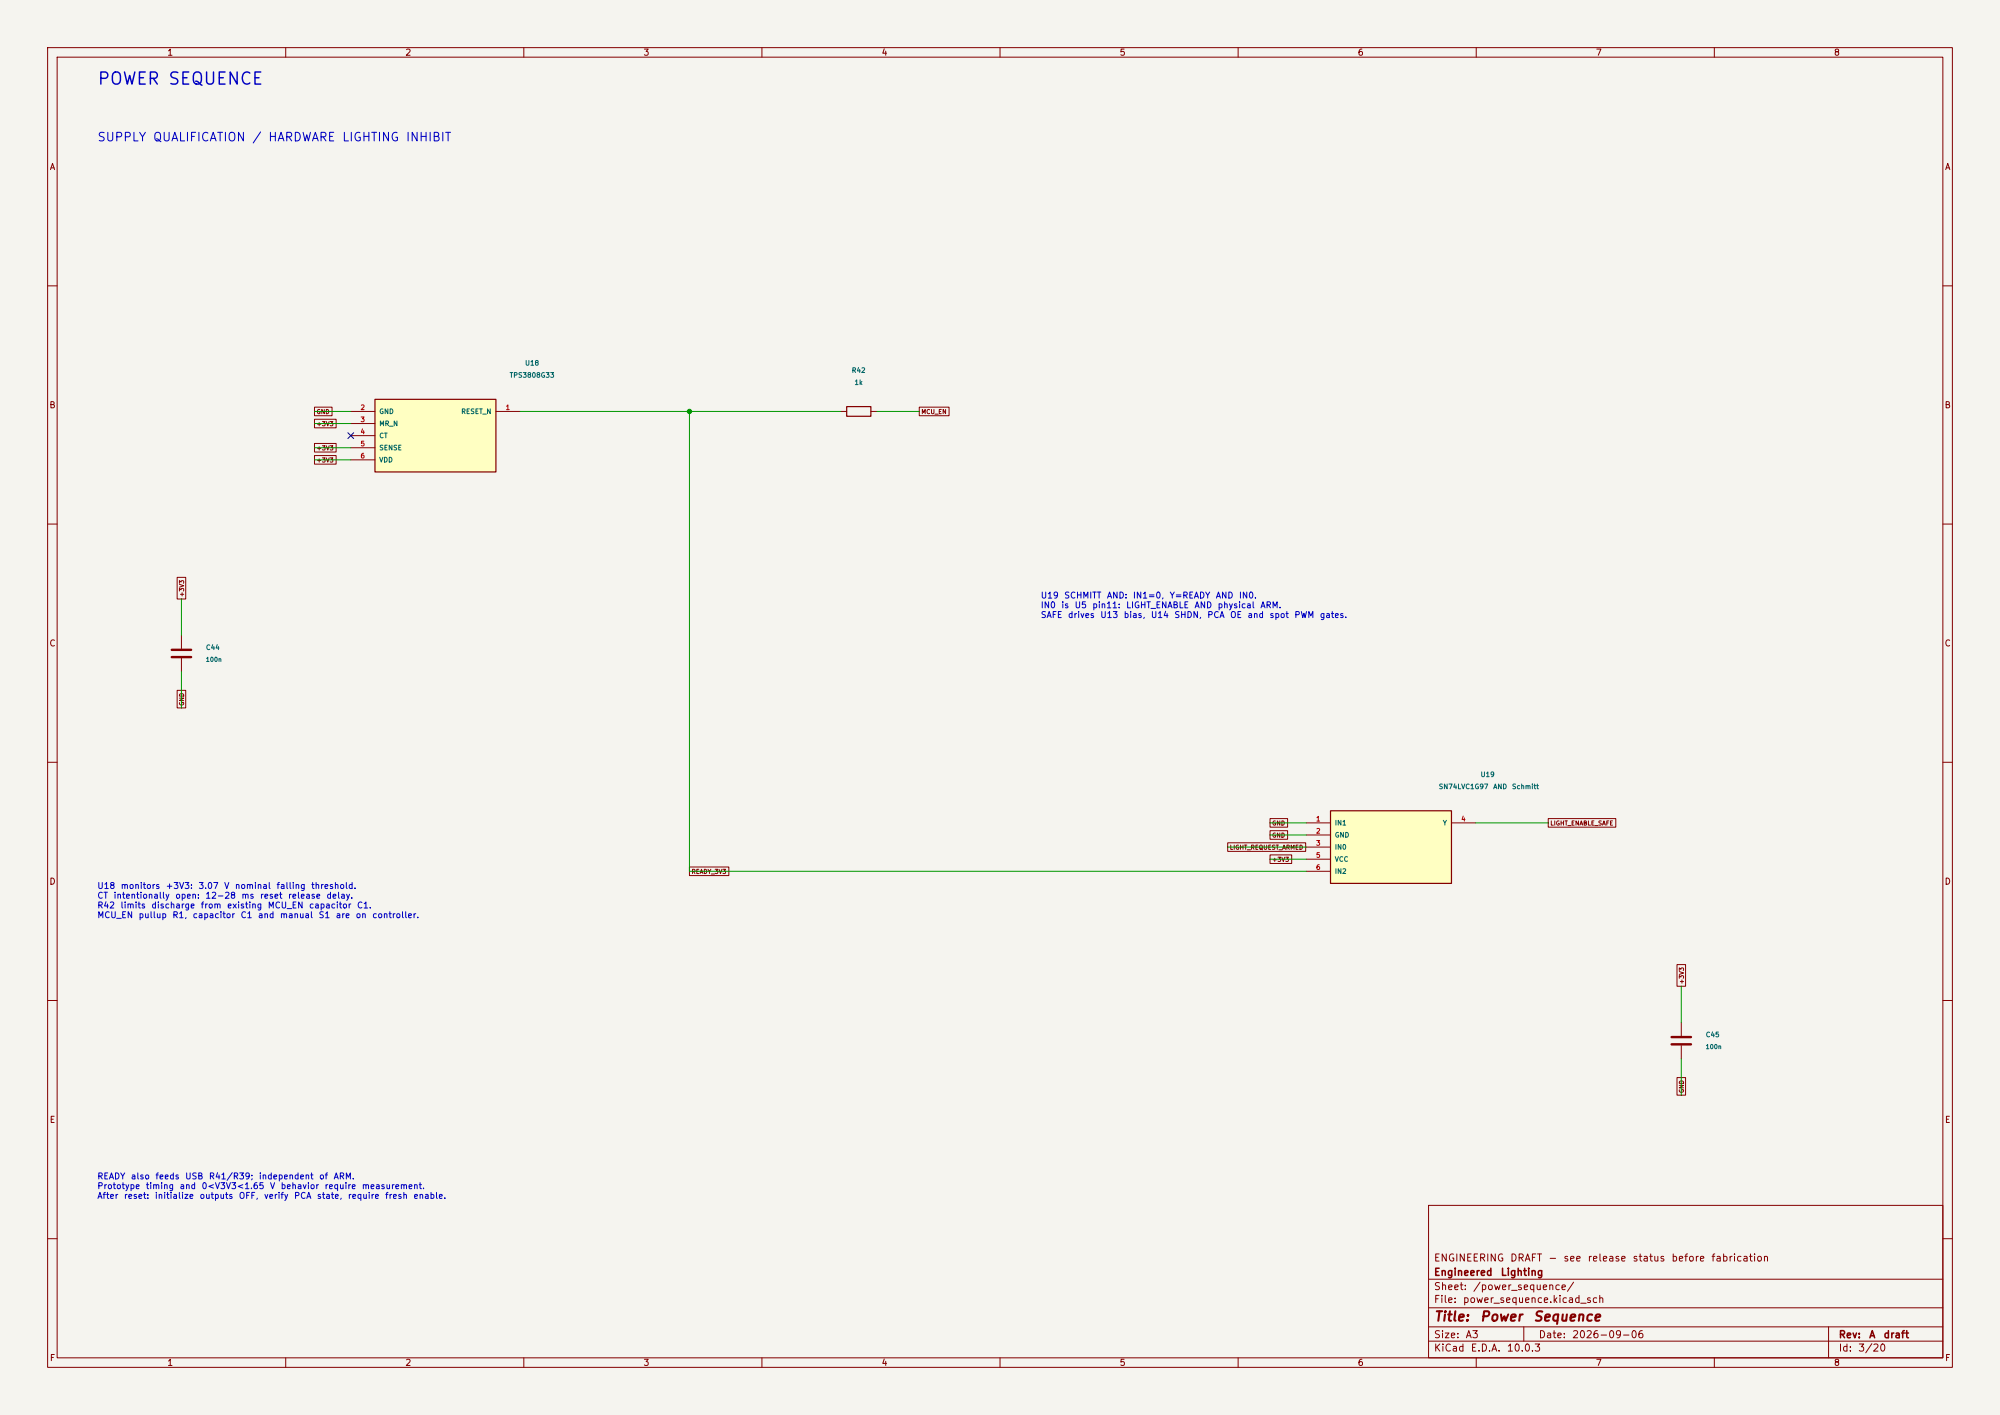
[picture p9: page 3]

SUPPLY QUALIFICATION / HARDWARE LIGHTING INHIBIT

MCU_EN U18 monitors +3V3: 3.07 V nominal falling threshold. CT intentionally open: 12-28 ms reset release delay. R42 limits discharge from existing MCU_EN capacitor C1. MCU_EN pullup R1, capacitor C1 and manual S1 are on controller.

U19 SCHMITT AND: IN1=0, Y=READY AND IN0.
IN0 is U5 pin11: LIGHT_ENABLE AND physical ARM. SAFE drives U13 bias, U14 SHDN, PCA OE and spot PWM gates.

READY also feeds USB R41/R39; independent of ARM. Prototype timing and 0<V3V3<1.65 V behavior require measurement. After reset: initialize outputs OFF, verify PCA state, require fresh enable.

ENGINEERING DRAFT - see release status before fabrication
Engineered Lighting
Sheet: /power_sequence/
File: power_sequence.kicad_sch
Title: Power Sequence

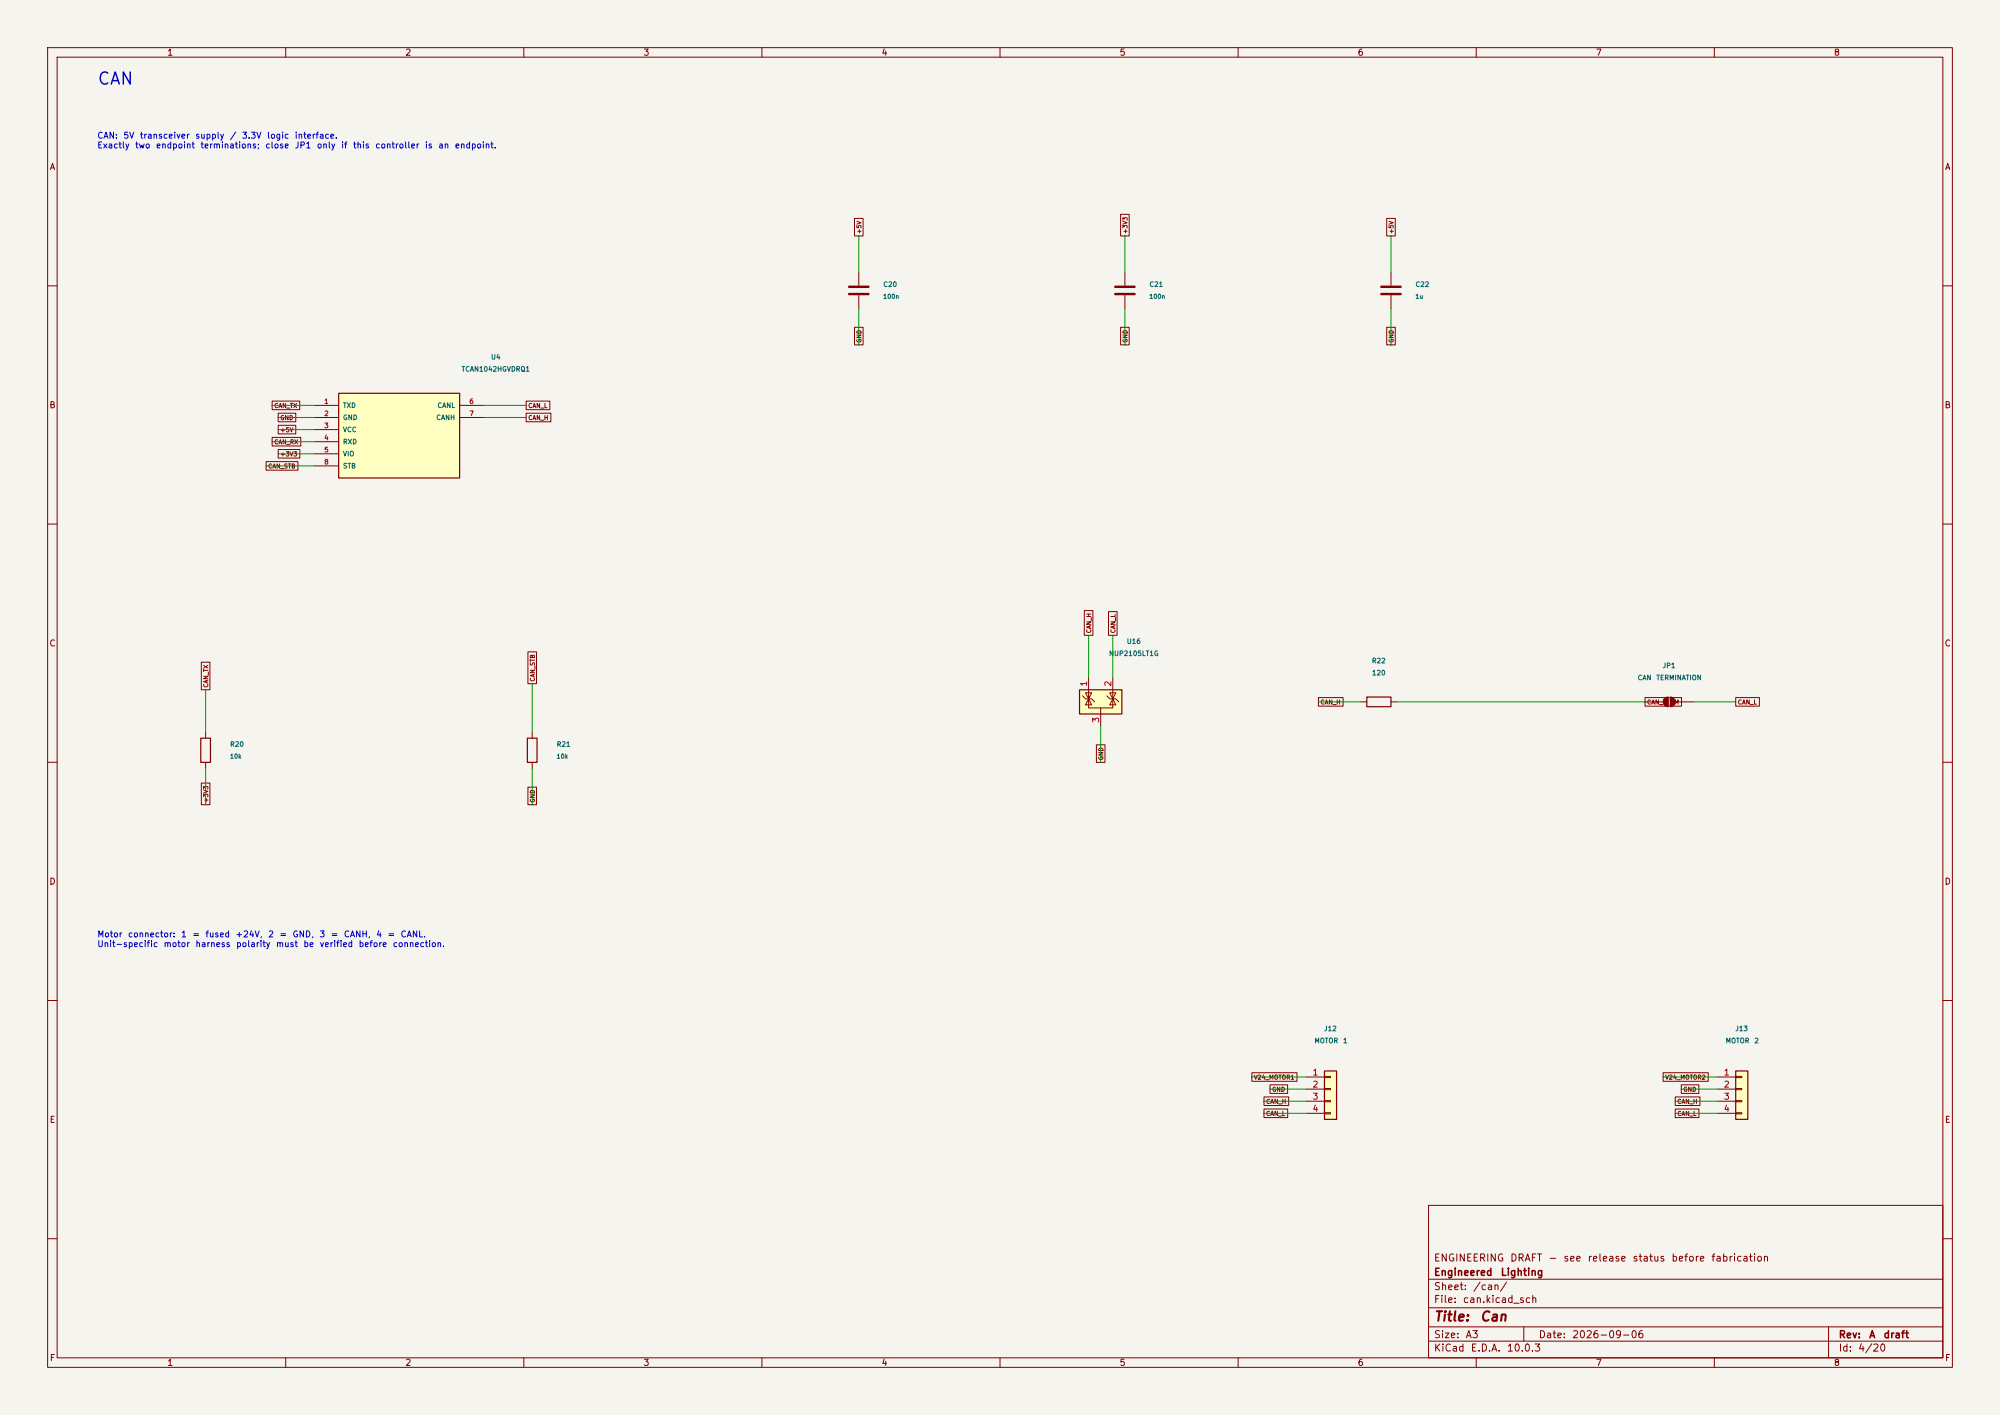
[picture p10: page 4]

CAN: 5V transceiver supply / 3.3V logic interface. Exactly two endpoint terminations; close JP1 only if this controller is an endpoint.

Motor connector: 1 = fused +24V, 2 = GND, 3 = CANH, 4 = CANL. Unit-specific motor harness polarity must be verified before connection.

ENGINEERING DRAFT - see release status before fabrication
Engineered Lighting
Sheet: /can/
File: can.kicad_sch
Title: Can

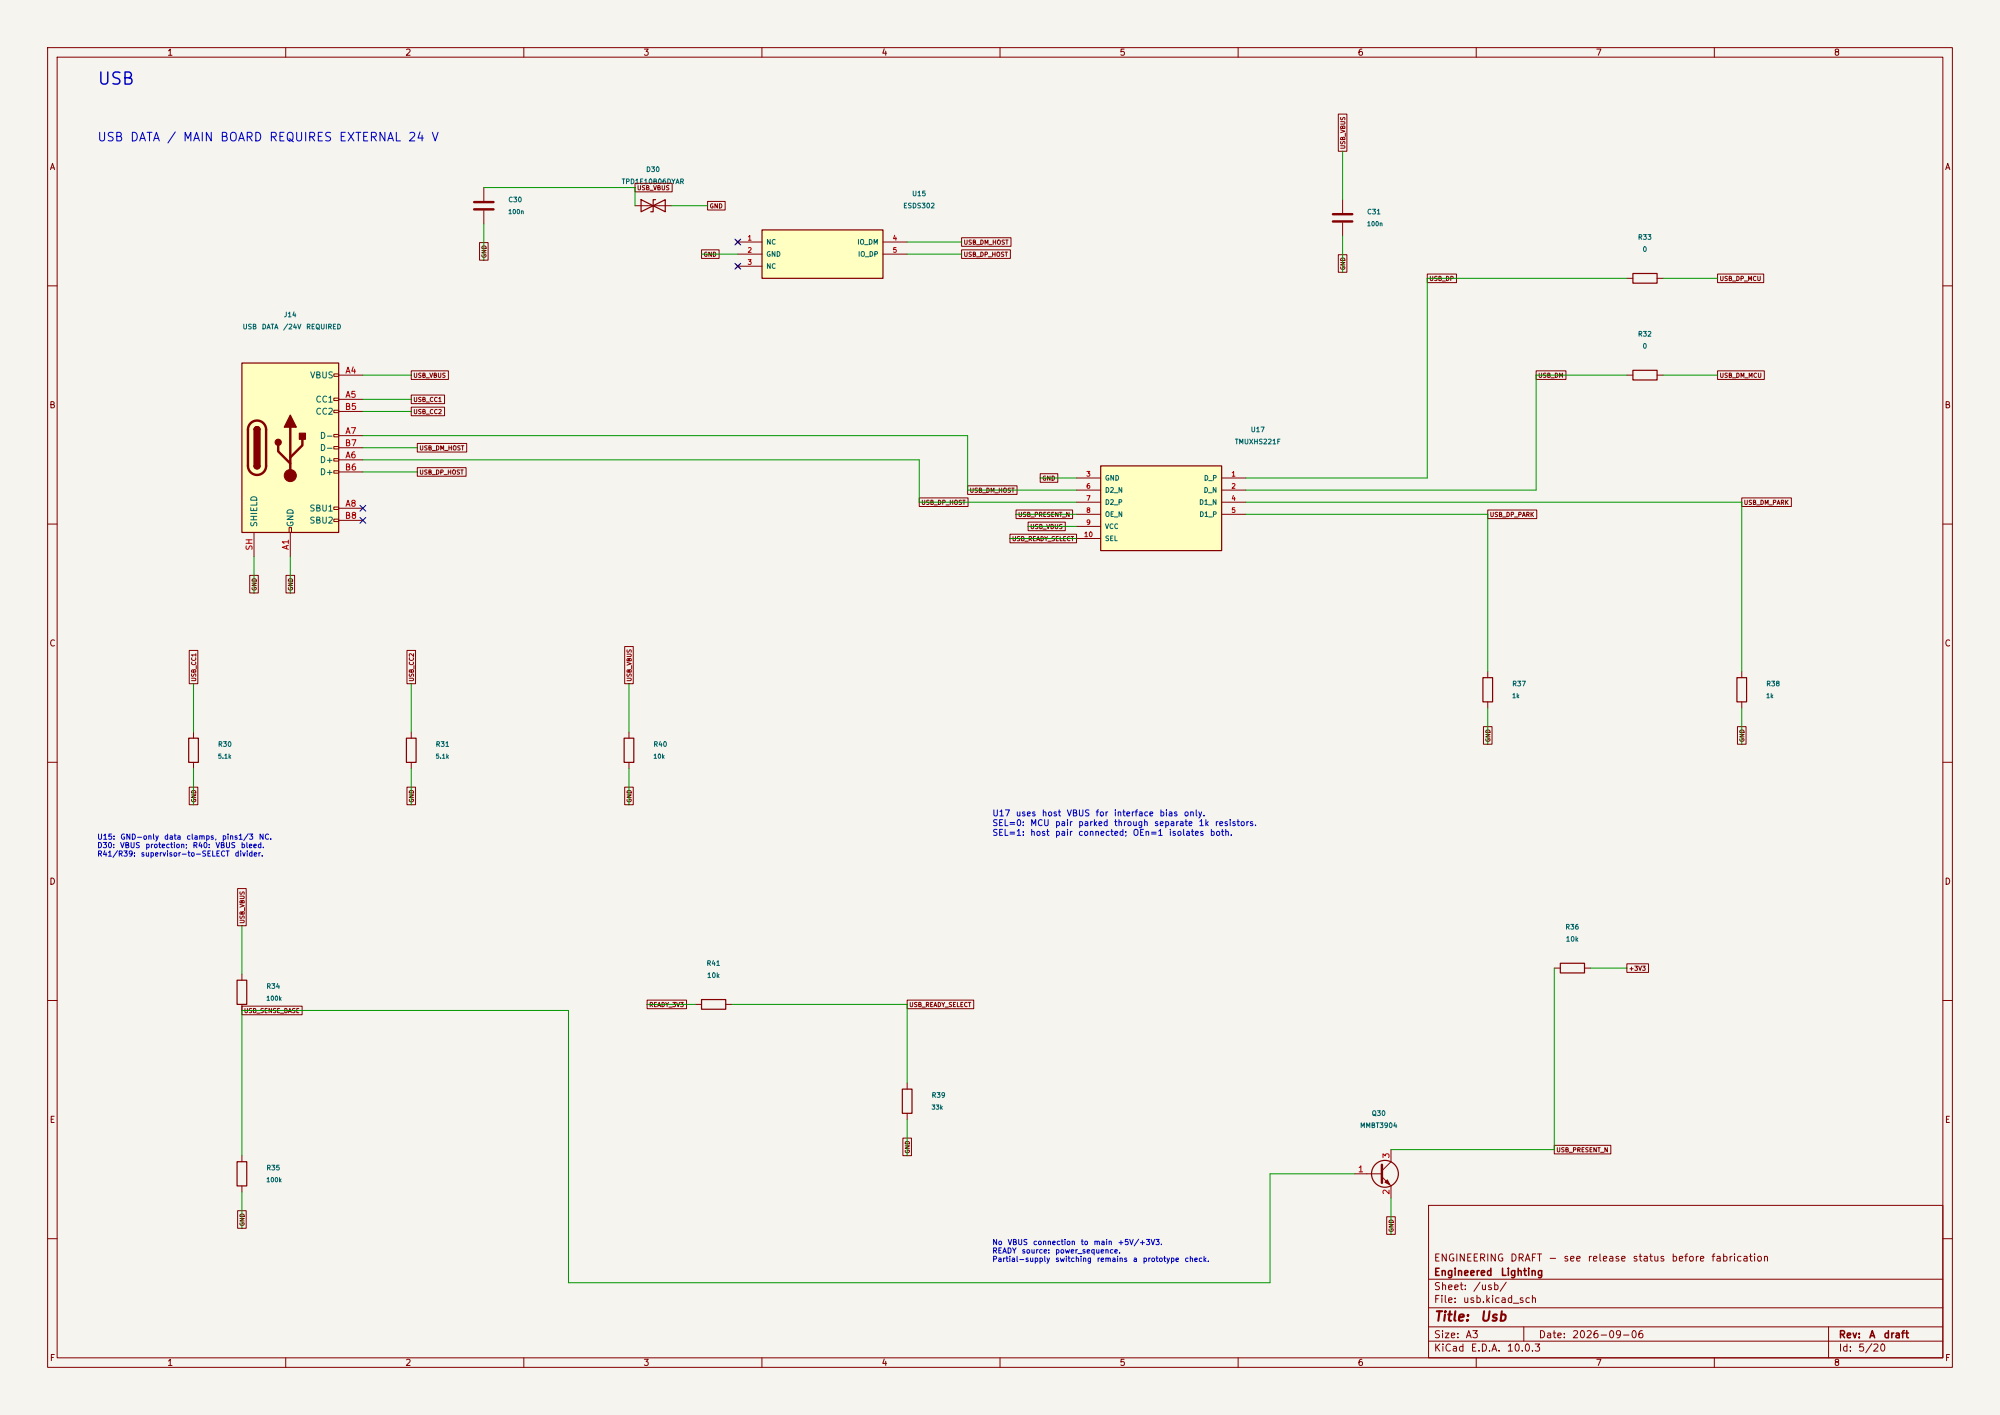
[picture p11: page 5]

USB DATA / MAIN BOARD REQUIRES EXTERNAL 24 V

ENGINEERING DRAFT - see release status before fabrication GND A1

No VBUS connection to main +5V/+3V3. READY source: power_sequence. Partial-supply switching remains a prototype check.

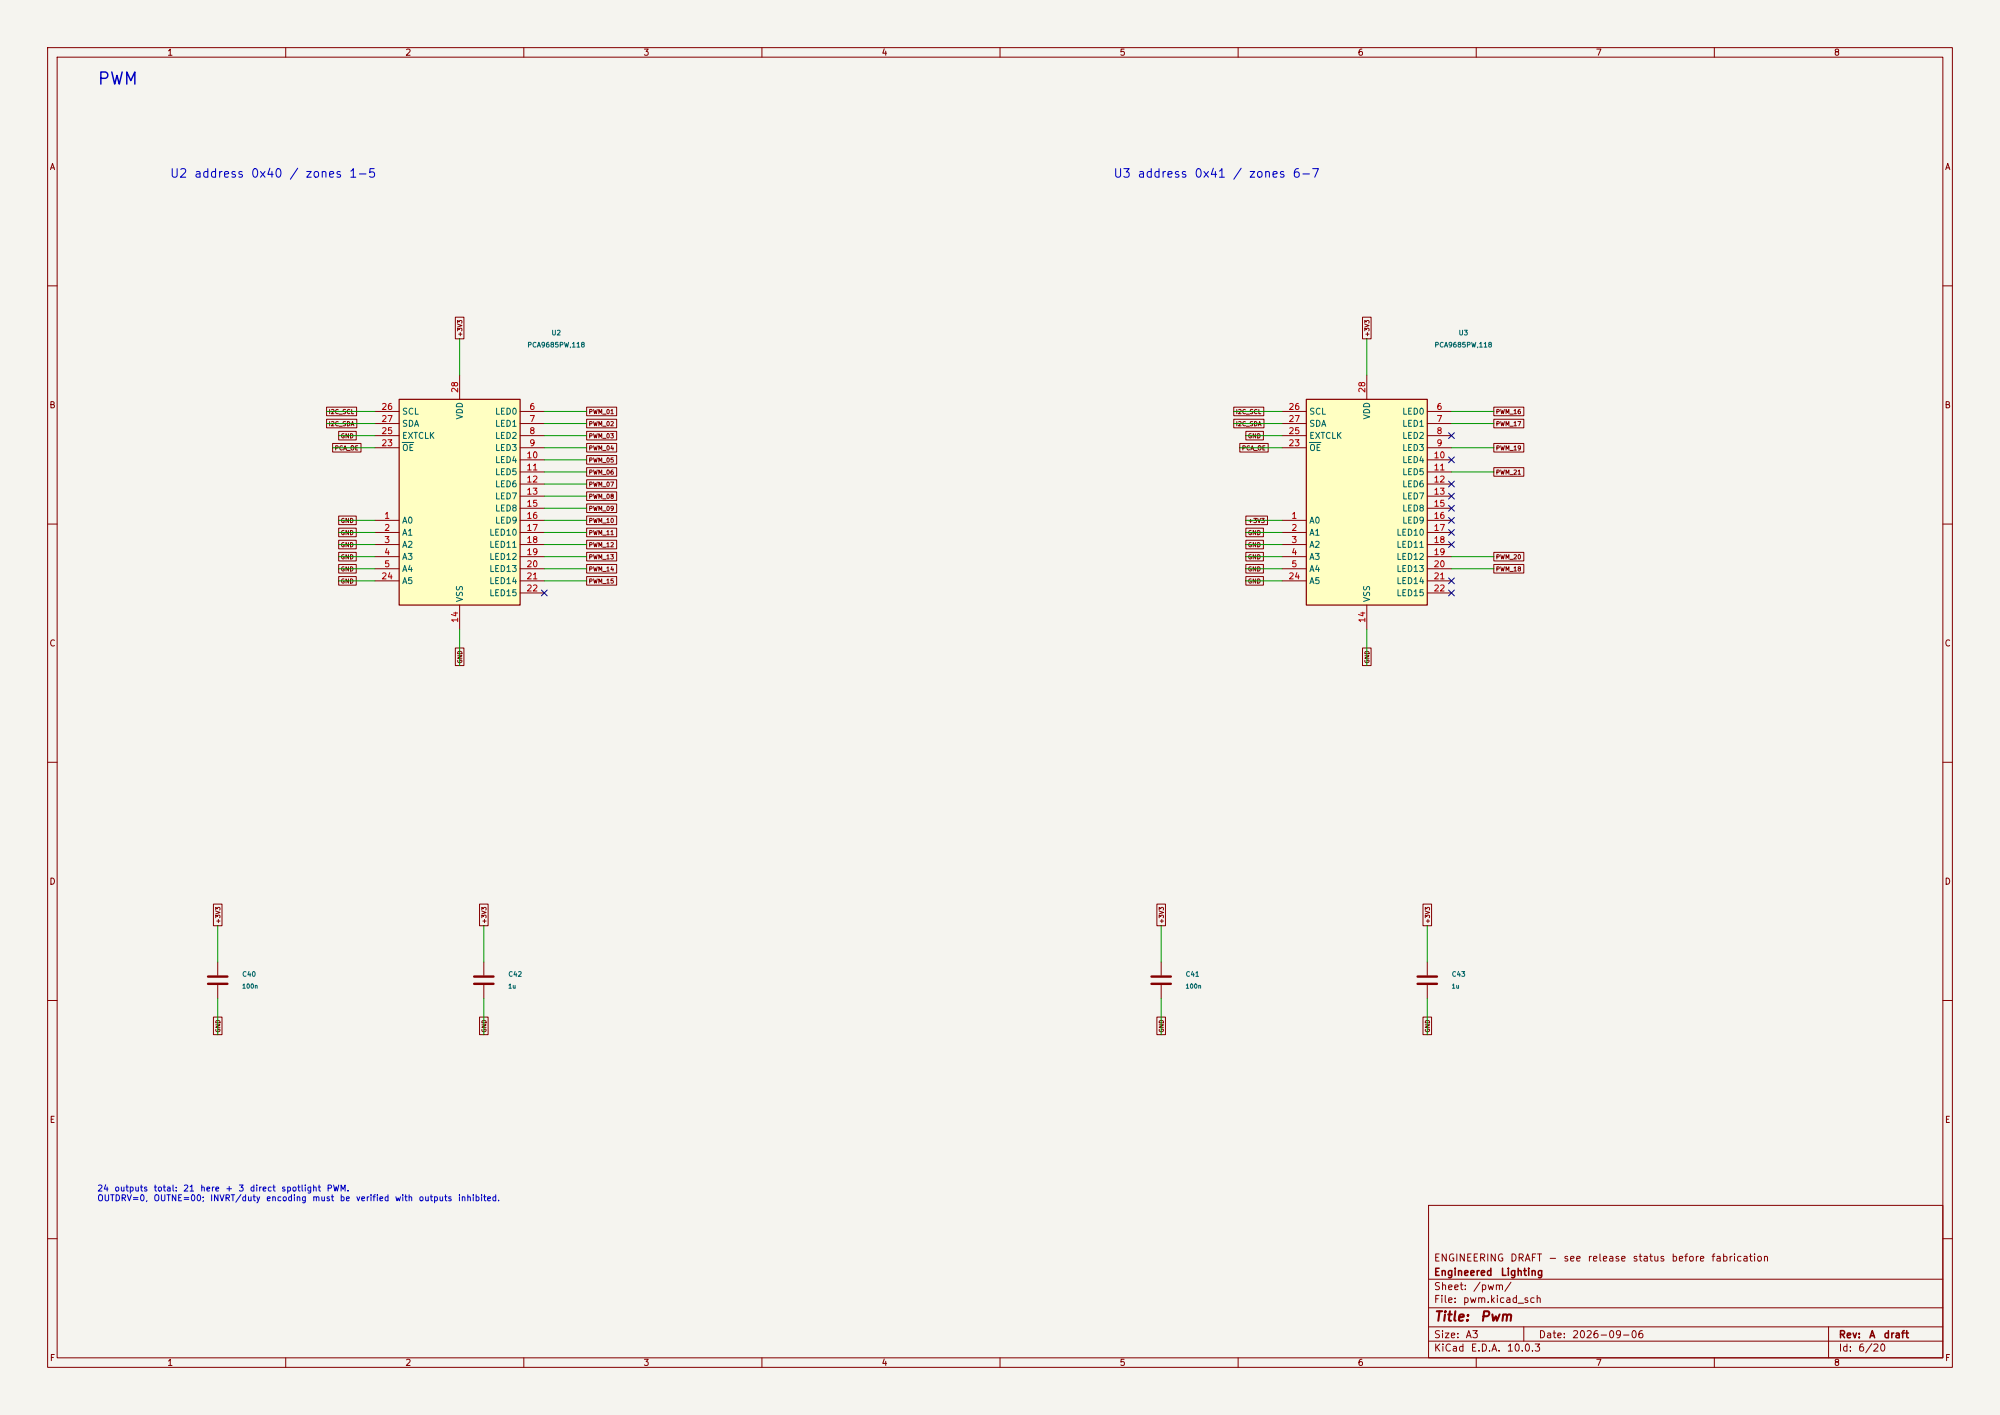
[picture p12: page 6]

24 outputs total: 21 here + 3 direct spotlight PWM. OUTDRV=0, OUTNE=00; INVRT/duty encoding must be verified with outputs inhibited.

ENGINEERING DRAFT - see release status before fabrication
Engineered Lighting
Sheet: /pwm/
File: pwm.kicad_sch
Title: Pwm

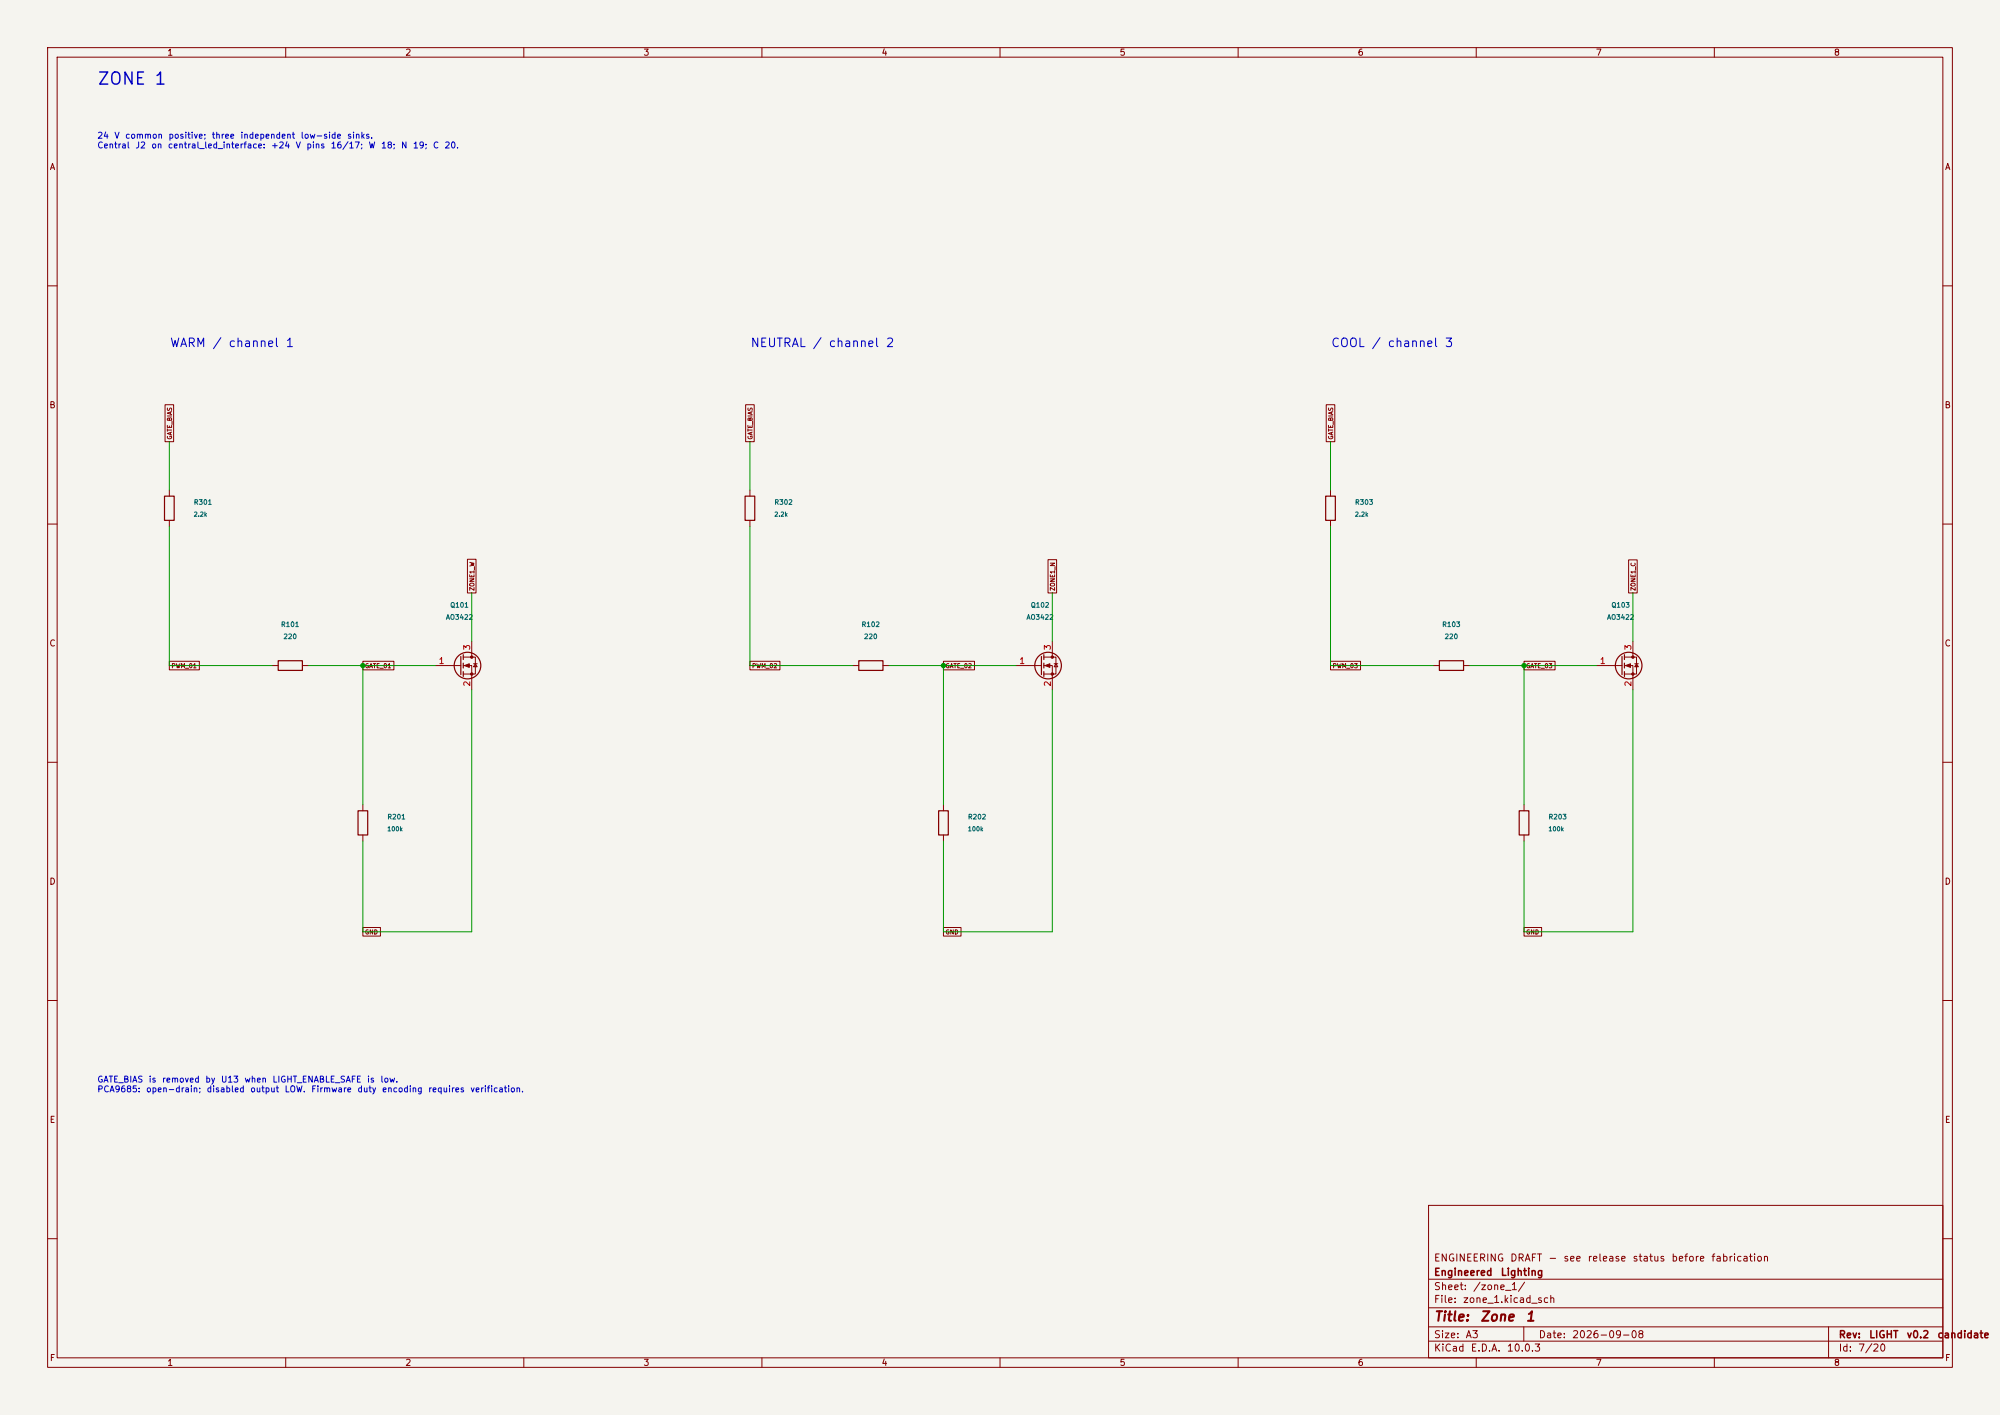
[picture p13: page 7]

24 V common positive; three independent low-side sinks. Central J2 on central_led_interface: +24 V pins 16/17; W 18; N 19; C 20. WARM / channel 1

GATE_BIAS is removed by U13 when LIGHT_ENABLE_SAFE is low. PCA9685: open-drain; disabled output LOW. Firmware duty encoding requires verification.

ENGINEERING DRAFT - see release status before fabrication
Engineered Lighting
Sheet: /zone_1/
File: zone_1.kicad_sch
Title: Zone 1
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

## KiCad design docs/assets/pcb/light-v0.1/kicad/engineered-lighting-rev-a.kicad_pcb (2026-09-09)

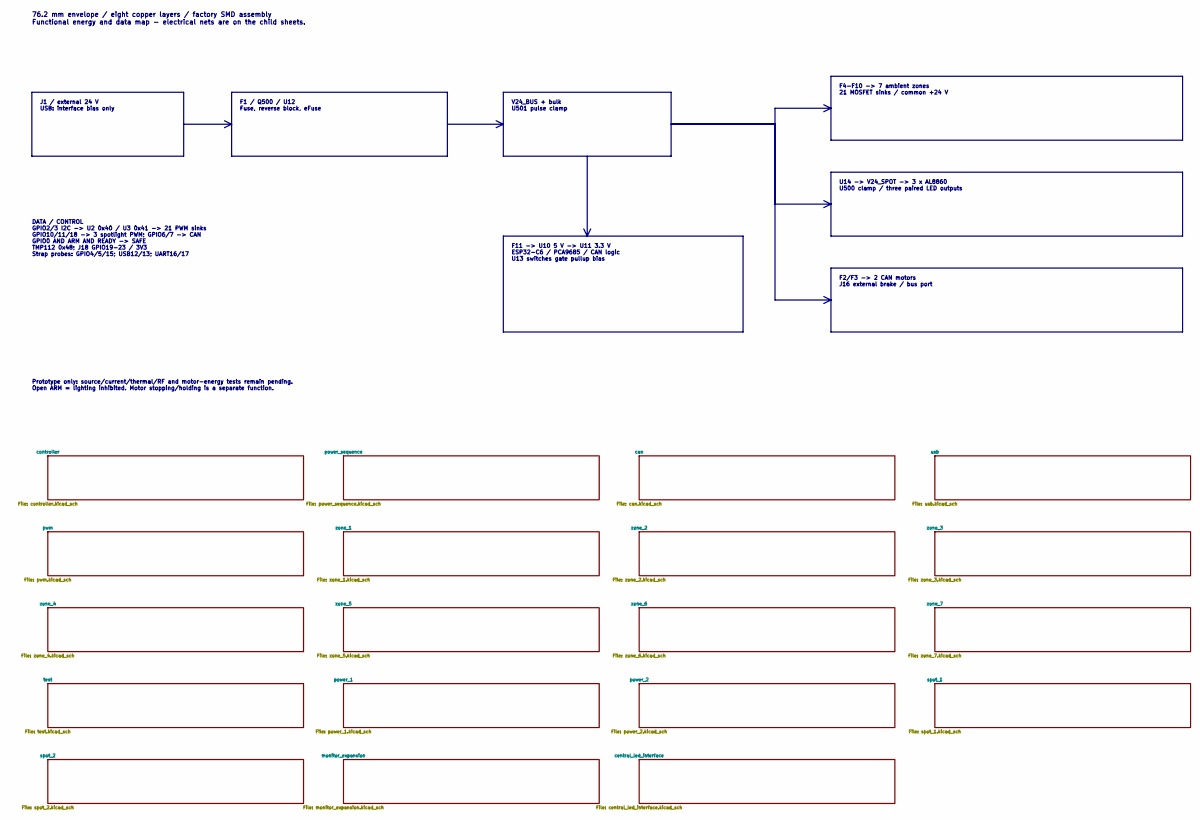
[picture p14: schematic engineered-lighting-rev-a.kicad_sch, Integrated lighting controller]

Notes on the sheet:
76.2 mm envelope / eight copper layers / factory SMD assembly Functional energy and data map - electrical nets are on the child sheets.
J1 / external 24 V USB: interface bias only
F1 / Q500 / U12 Fuse, reverse block, eFuse
V24_BUS + bulk U501 pulse clamp
F4-F10 -> 7 ambient zones 21 MOSFET sinks / common +24 V
U14 -> V24_SPOT -> 3 x AL8860 U500 clamp / three paired LED outputs
F2/F3 -> 2 CAN motors J16 external brake / bus port
F11 -> U10 5 V -> U11 3.3 V ESP32-C6 / PCA9685 / CAN logic U13 switches gate pullup bias
DATA / CONTROL GPIO2/3 I2C -> U2 0x40 / U3 0x41 -> 21 PWM sinks GPIO10/11/18 -> 3 spotlight PWM; GPIO6/7 -> CAN GPIO0 AND ARM AND READY -> SAFE TMP112 0x48; J18 GPIO19-23 / 3V3 Strap probes: GPIO4/5/15; USB12/13; UART16/17
Prototype only: source/current/thermal/RF and motor-energy tests remain pending. Open ARM = lighting inhibited. Motor stopping/holding is a separate function.

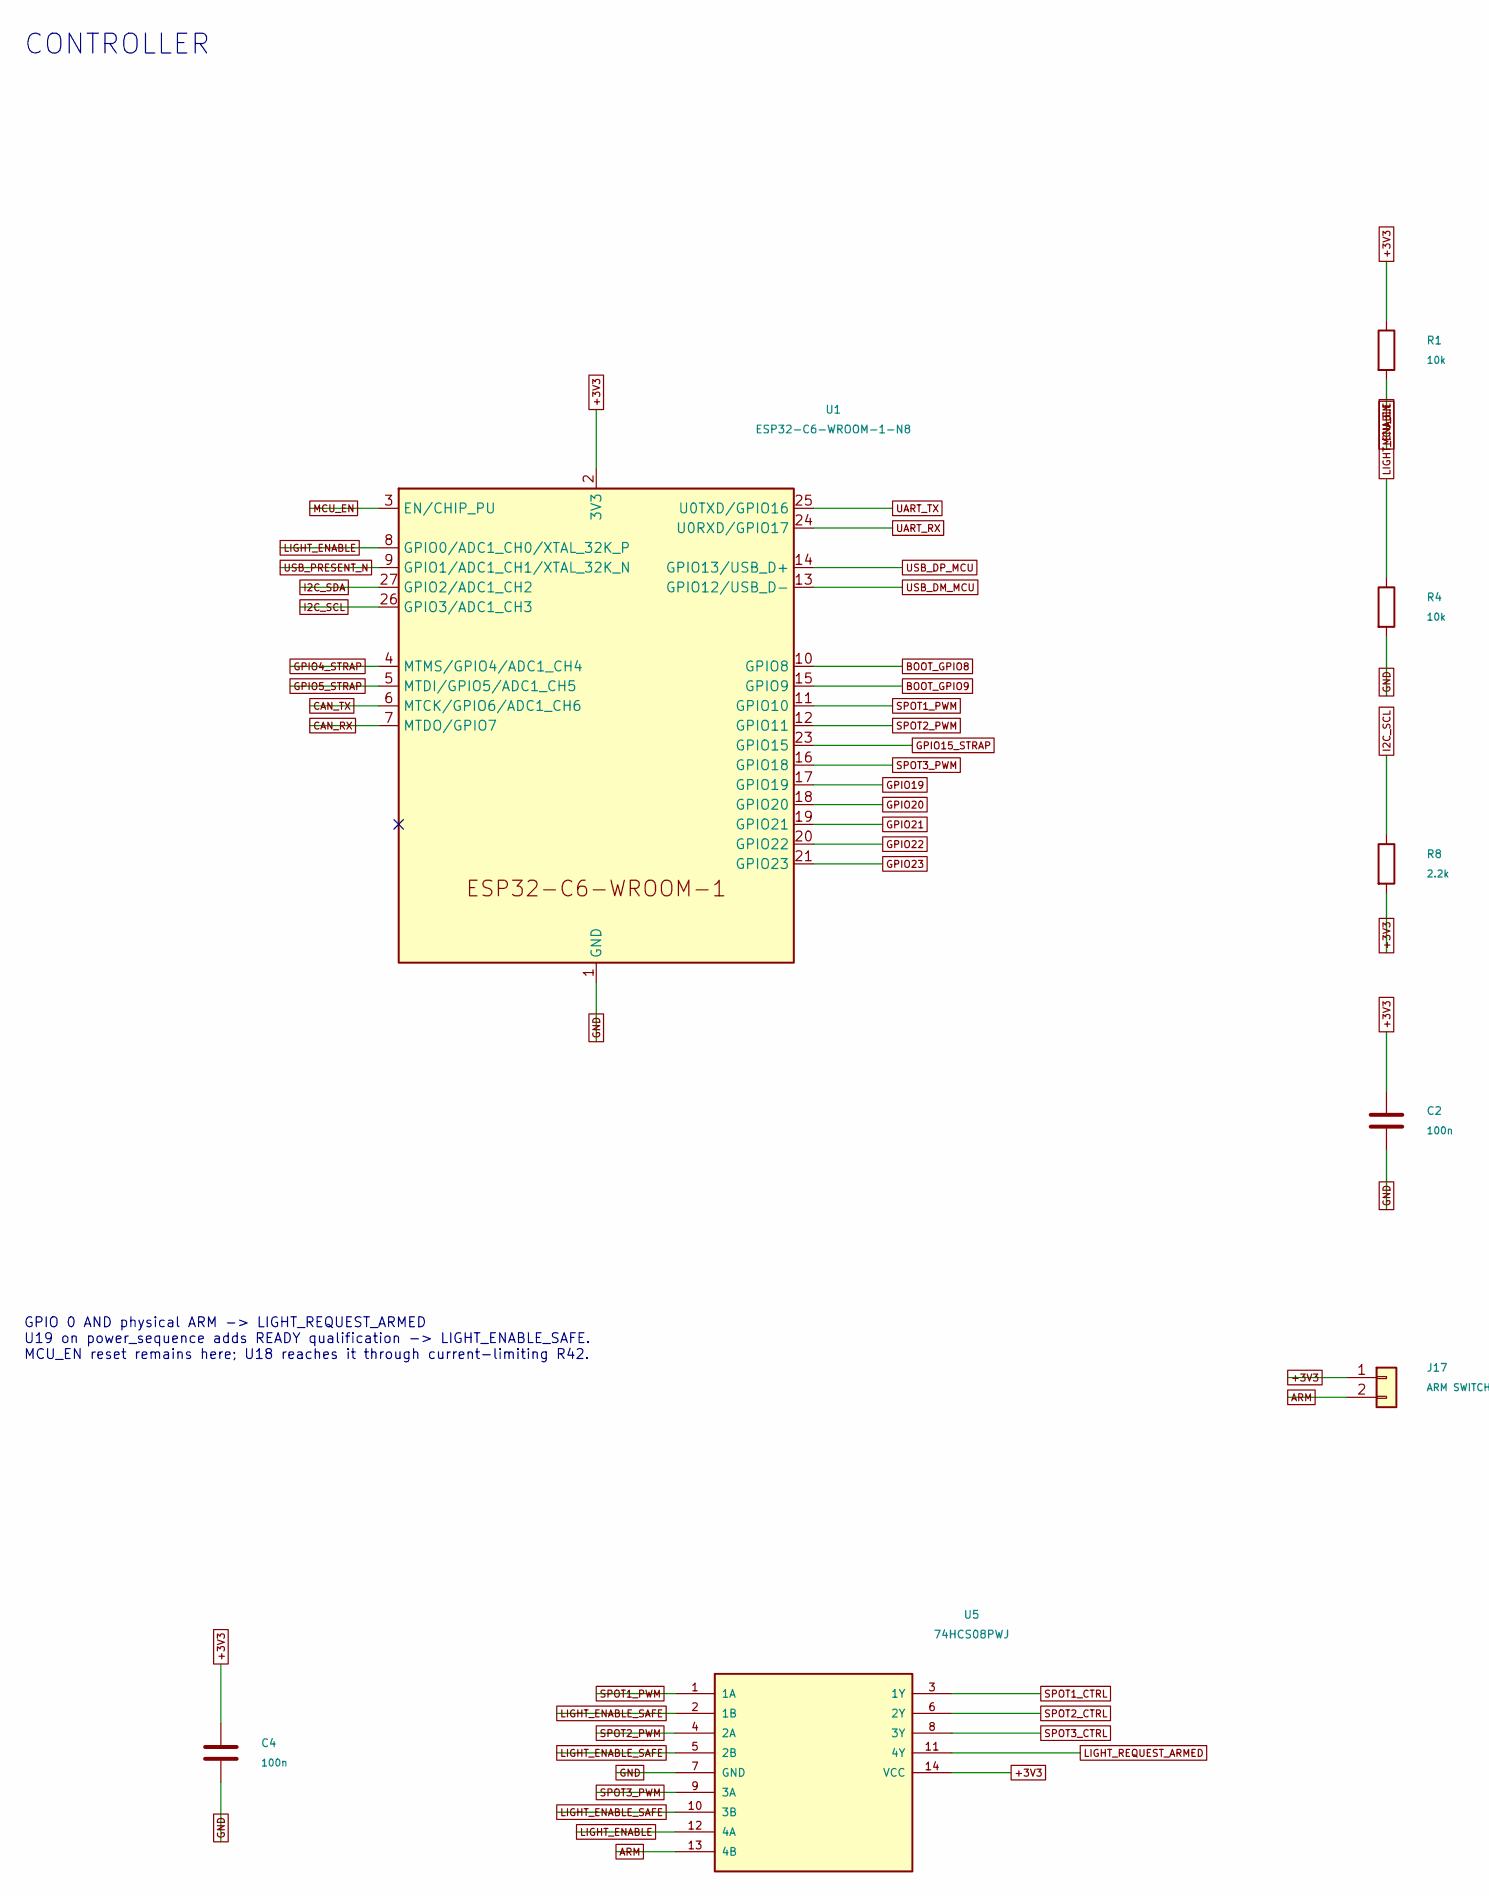
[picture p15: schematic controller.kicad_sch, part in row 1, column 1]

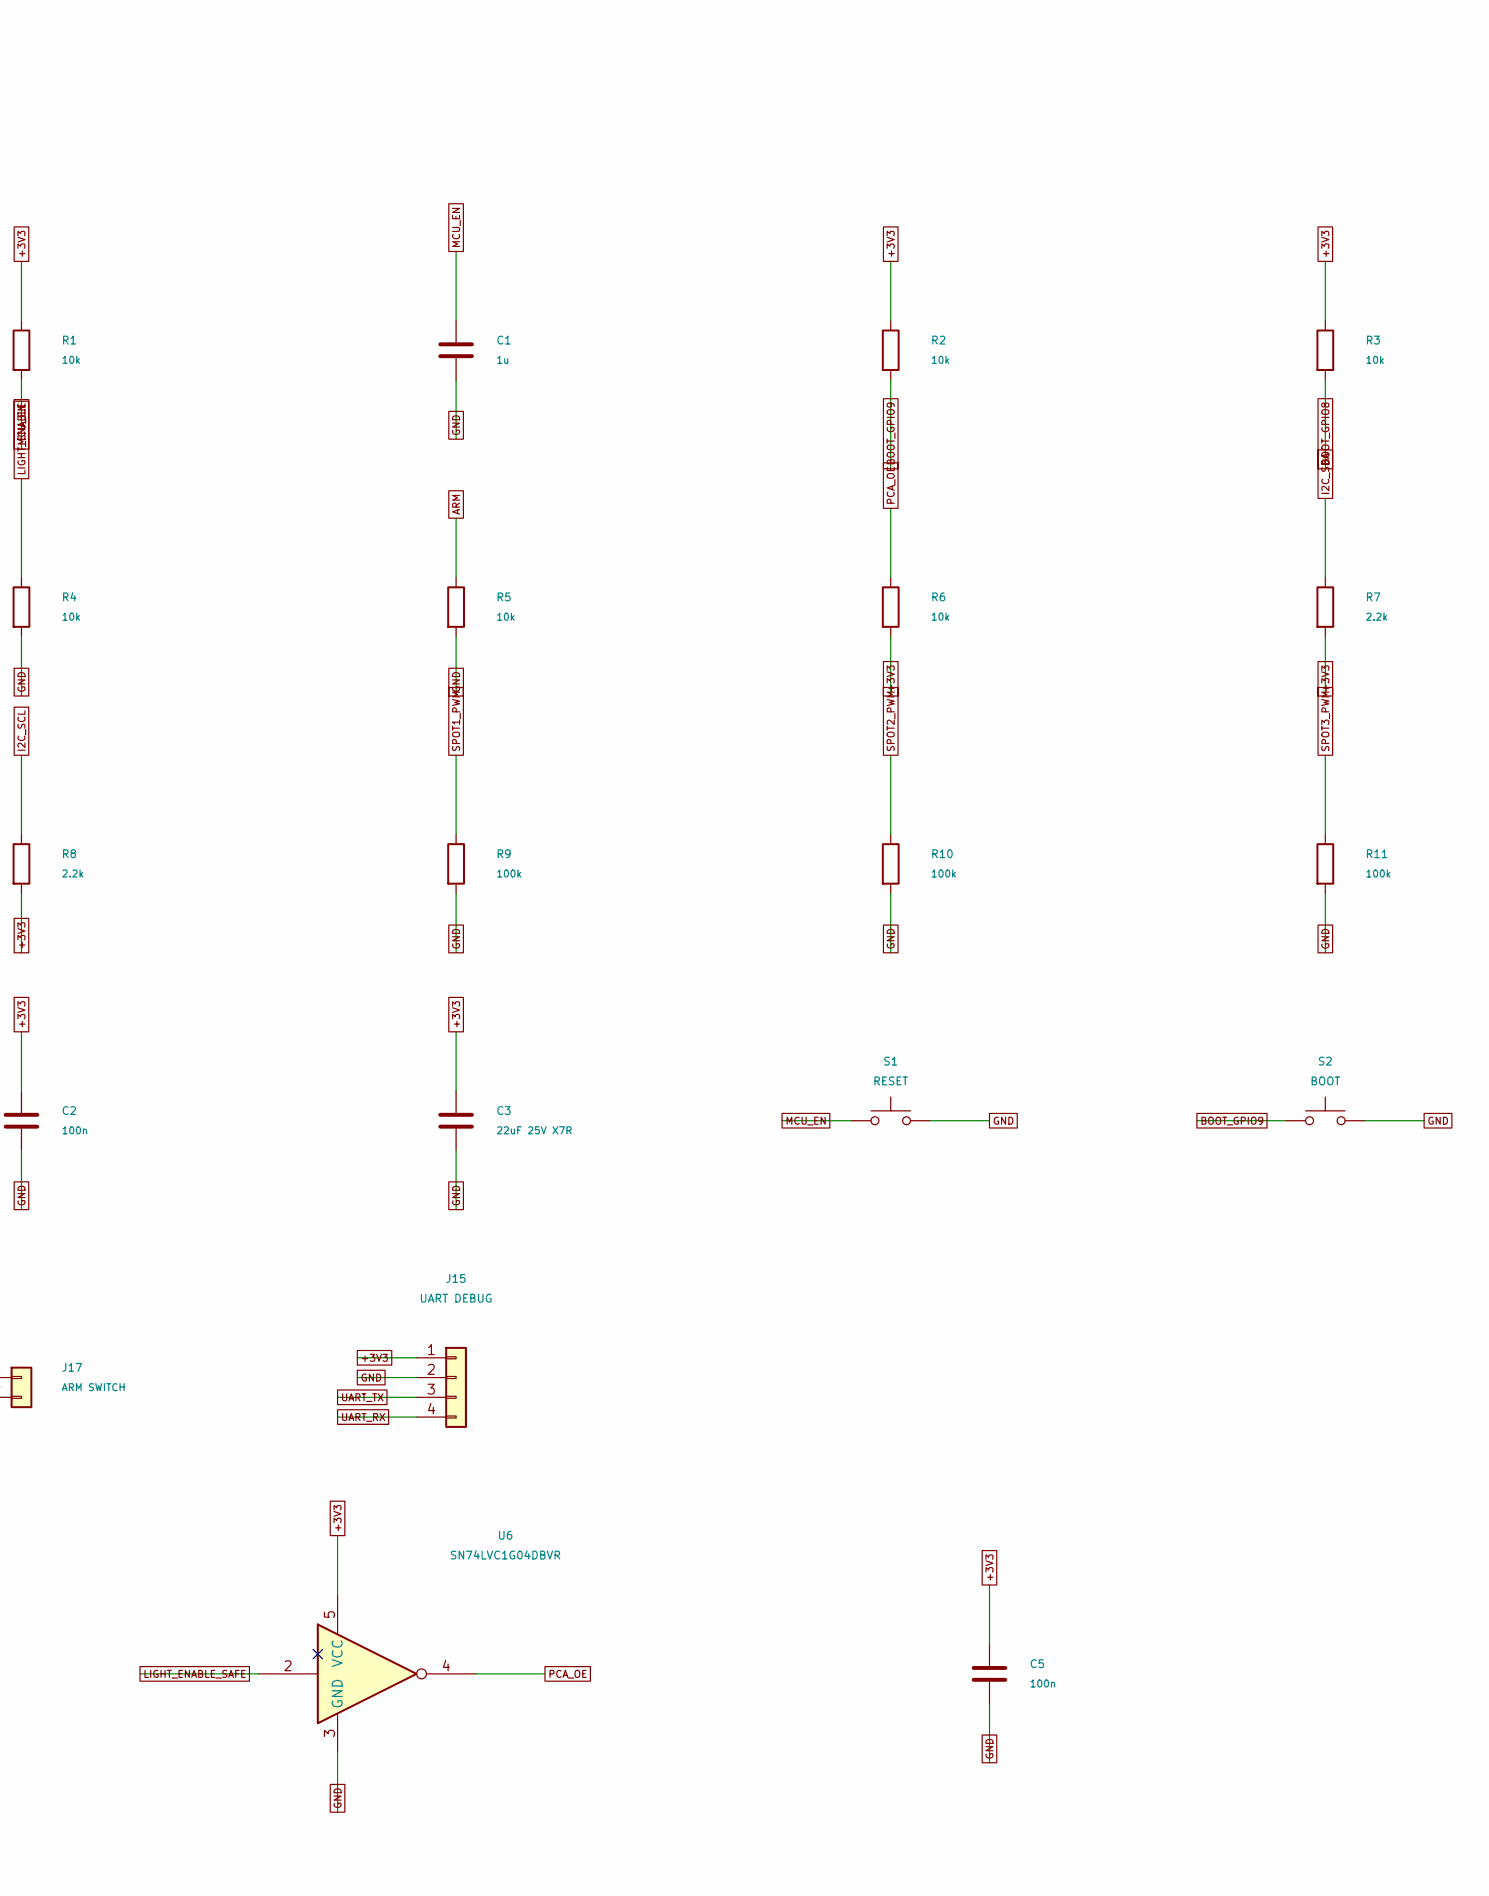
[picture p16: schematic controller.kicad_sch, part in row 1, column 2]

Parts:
C1: 1u; C_0603_1608Metric; MPN C1608X7R1E105K080AB
C2, C4, C5: 100n; C_0603_1608Metric; MPN GRM188R72A104KA35D
C3: 22uF 25V X7R; C_1210_3225Metric; MPN GRM32ER71E226KE15L
J15: UART DEBUG; JST_SH_SM04B-SRSS-TB_1x04-1MP_P1.00mm_Horizontal; MPN SM04B-SRSS-TB(LF)(SN)
J17: ARM SWITCH; Enclosure_J17; MPN B2B-PH-SM4-TB(LF)(SN)
R1, R2, R3, R4, R5, R6: 10k; R_0603_1608Metric; MPN RC0603FR-0710KL
R7, R8: 2.2k; R_0603_1608Metric; MPN RC0603FR-072K2L
R9, R10, R11: 100k; R_0603_1608Metric; MPN RC0603FR-07100KL
S1: RESET; SW_SPST_TL3305A; MPN TL3305AF160QG
S2: BOOT; SW_SPST_TL3305A; MPN TL3305AF160QG
U1: ESP32-C6-WROOM-1-N8; ESP32-C6-WROOM-1; MPN ESP32-C6-WROOM-1-N8
U5: 74HCS08PWJ; TSSOP-14_4.4x5mm_P0.65mm; MPN 74HCS08PWJ
U6: SN74LVC1G04DBVR; SOT-23-5; MPN SN74LVC1G04DBVR

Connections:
+3V3: C2.1, C3.1, C4.1, C5.1, J15.1, J17.1, R1.1, R2.1, R3.1, R6.2, R7.2, R8.2, U1.2 (3V3), U5.14 (VCC), U6.5 (VCC); also elsewhere on the board
ARM: J17.2, R5.1, U5.13 (4B)
BOOT_GPIO8: R3.2, U1.10 (GPIO8)
BOOT_GPIO9: R2.2, S2.1, U1.15 (GPIO9)
CAN_RX: U1.7 (MTDO/GPIO7); also elsewhere on the board
CAN_TX: U1.6 (MTCK/GPIO6/ADC1_CH6); also elsewhere on the board
GND: C1.2, C2.2, C3.2, C4.2, C5.2, J15.2, R4.2, R5.2, R9.2, R10.2, R11.2, S1.2, S2.2, U1.1 (GND), U1.28 (GND), U1.29 (GND), U5.7 (GND), U6.3 (GND); also elsewhere on the board
GPIO4_STRAP: U1.4 (MTMS/GPIO4/ADC1_CH4); also elsewhere on the board
GPIO5_STRAP: U1.5 (MTDI/GPIO5/ADC1_CH5); also elsewhere on the board
GPIO15_STRAP: U1.23 (GPIO15); also elsewhere on the board
GPIO19: U1.17 (GPIO19); also elsewhere on the board
GPIO20: U1.18 (GPIO20); also elsewhere on the board
GPIO21: U1.19 (GPIO21); also elsewhere on the board
GPIO22: U1.20 (GPIO22); also elsewhere on the board
GPIO23: U1.21 (GPIO23); also elsewhere on the board
I2C_SCL: R8.1, U1.26 (GPIO3/ADC1_CH3); also elsewhere on the board
I2C_SDA: R7.1, U1.27 (GPIO2/ADC1_CH2); also elsewhere on the board
LIGHT_ENABLE: R4.1, U1.8 (GPIO0/ADC1_CH0/XTAL_32K_P), U5.12 (4A)
LIGHT_ENABLE_SAFE: U5.2 (1B), U5.5 (2B), U5.10 (3B), U6.2; also elsewhere on the board
LIGHT_REQUEST_ARMED: U5.11 (4Y); also elsewhere on the board
MCU_EN: C1.1, R1.2, S1.1, U1.3 (EN/CHIP_PU); also elsewhere on the board
PCA_OE: R6.1, U6.4; also elsewhere on the board
SPOT1_CTRL: U5.3 (1Y); also elsewhere on the board
SPOT1_PWM: R9.1, U1.11 (GPIO10), U5.1 (1A)
SPOT2_CTRL: U5.6 (2Y); also elsewhere on the board
SPOT2_PWM: R10.1, U1.12 (GPIO11), U5.4 (2A)
SPOT3_CTRL: U5.8 (3Y); also elsewhere on the board
SPOT3_PWM: R11.1, U1.16 (GPIO18), U5.9 (3A)
UART_RX: J15.4, U1.24 (U0RXD/GPIO17)
UART_TX: J15.3, U1.25 (U0TXD/GPIO16)
USB_DM_MCU: U1.13 (GPIO12/USB_D-); also elsewhere on the board
USB_DP_MCU: U1.14 (GPIO13/USB_D+); also elsewhere on the board
USB_PRESENT_N: U1.9 (GPIO1/ADC1_CH1/XTAL_32K_N); also elsewhere on the board

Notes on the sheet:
CONTROLLER
GPIO 0 AND physical ARM -> LIGHT_REQUEST_ARMED U19 on power_sequence adds READY qualification -> LIGHT_ENABLE_SAFE. MCU_EN reset remains here; U18 reaches it through current-limiting R42.

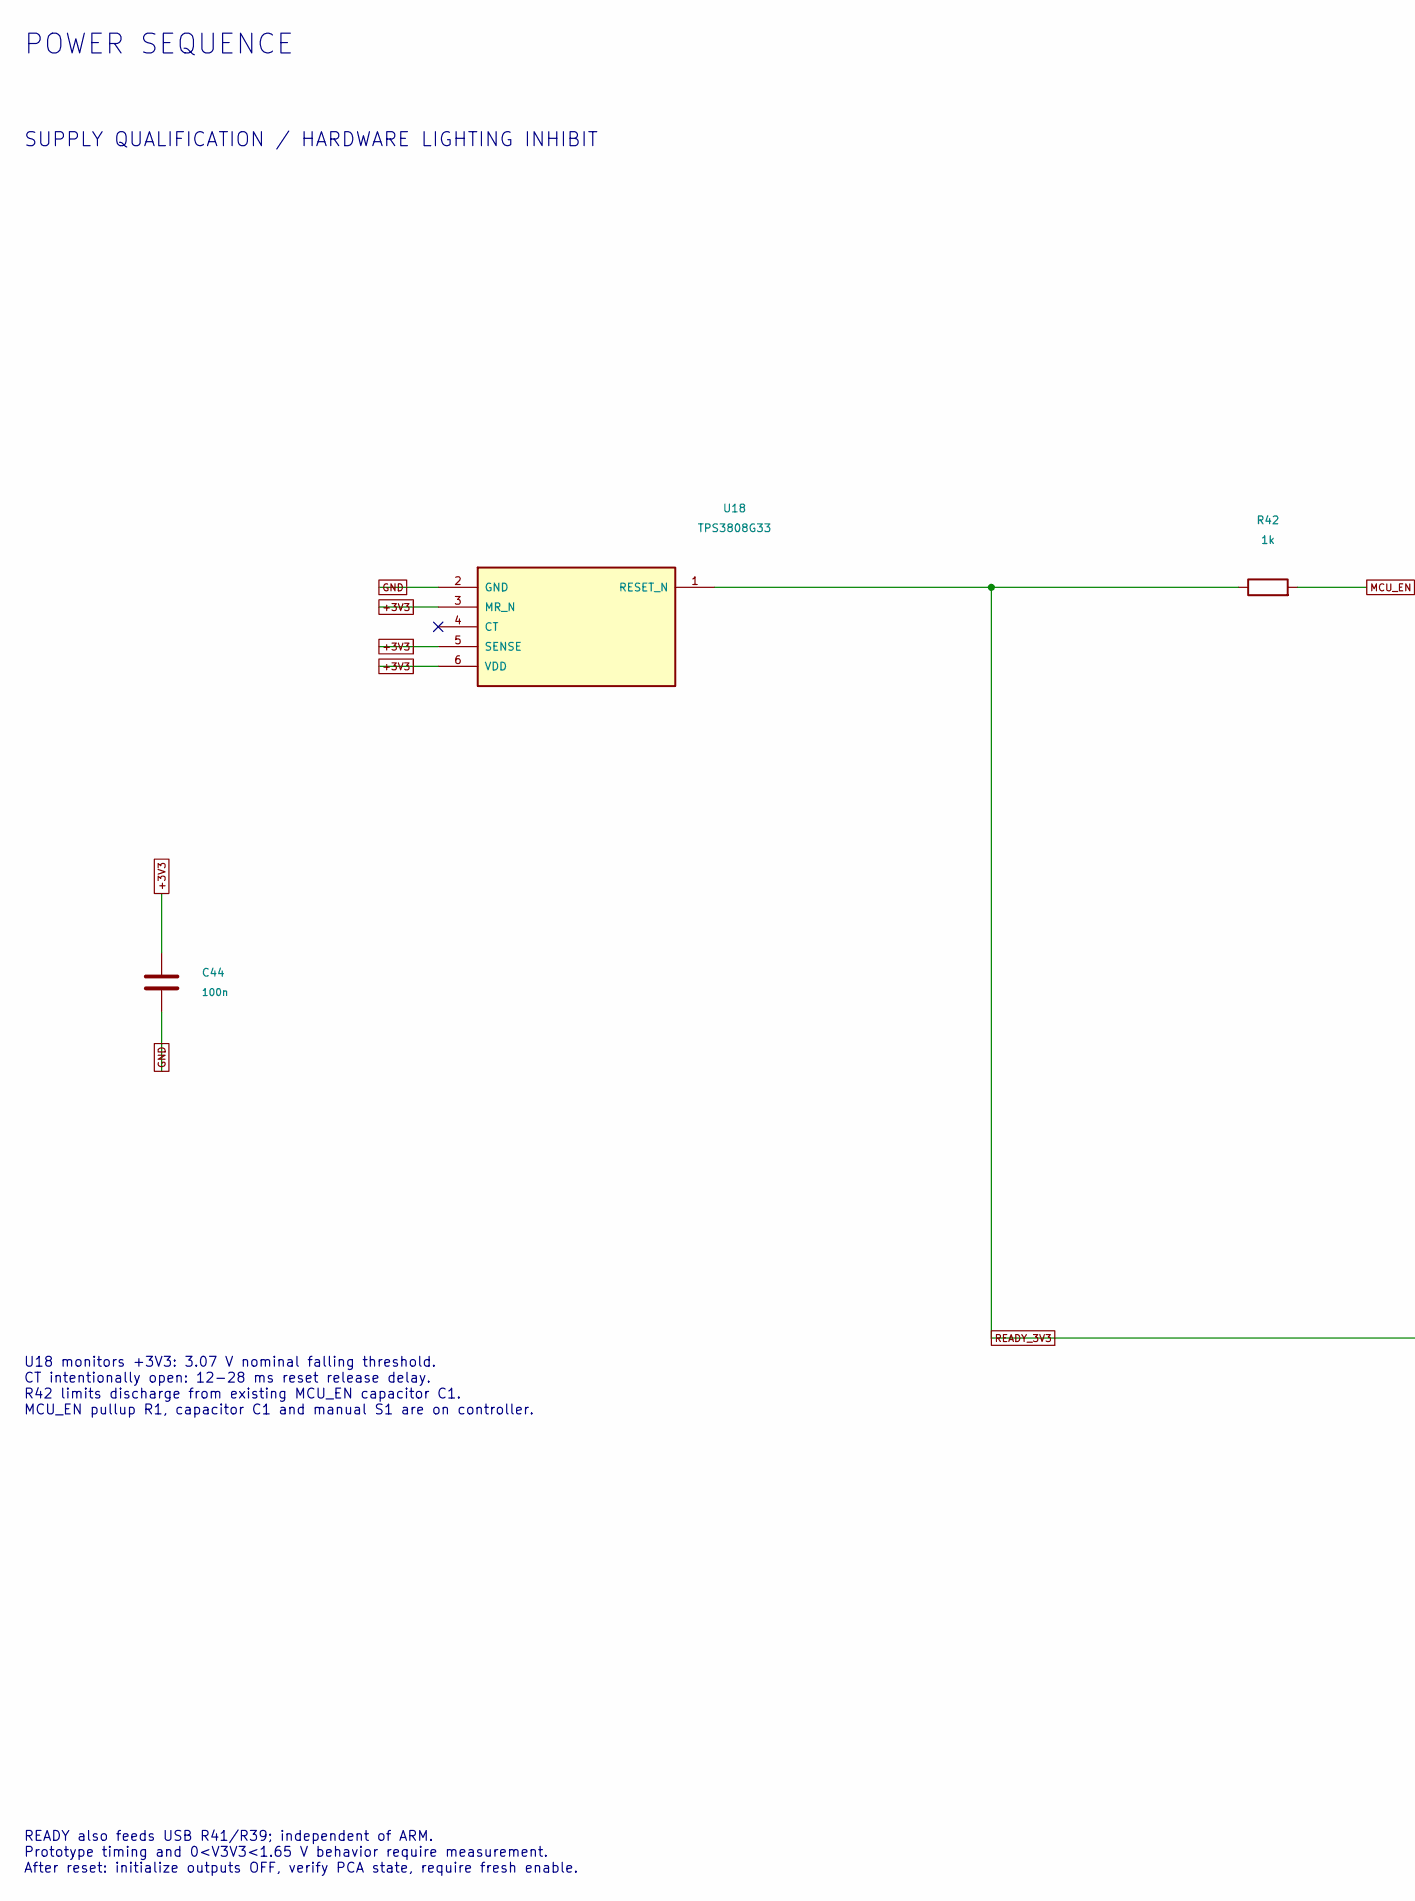
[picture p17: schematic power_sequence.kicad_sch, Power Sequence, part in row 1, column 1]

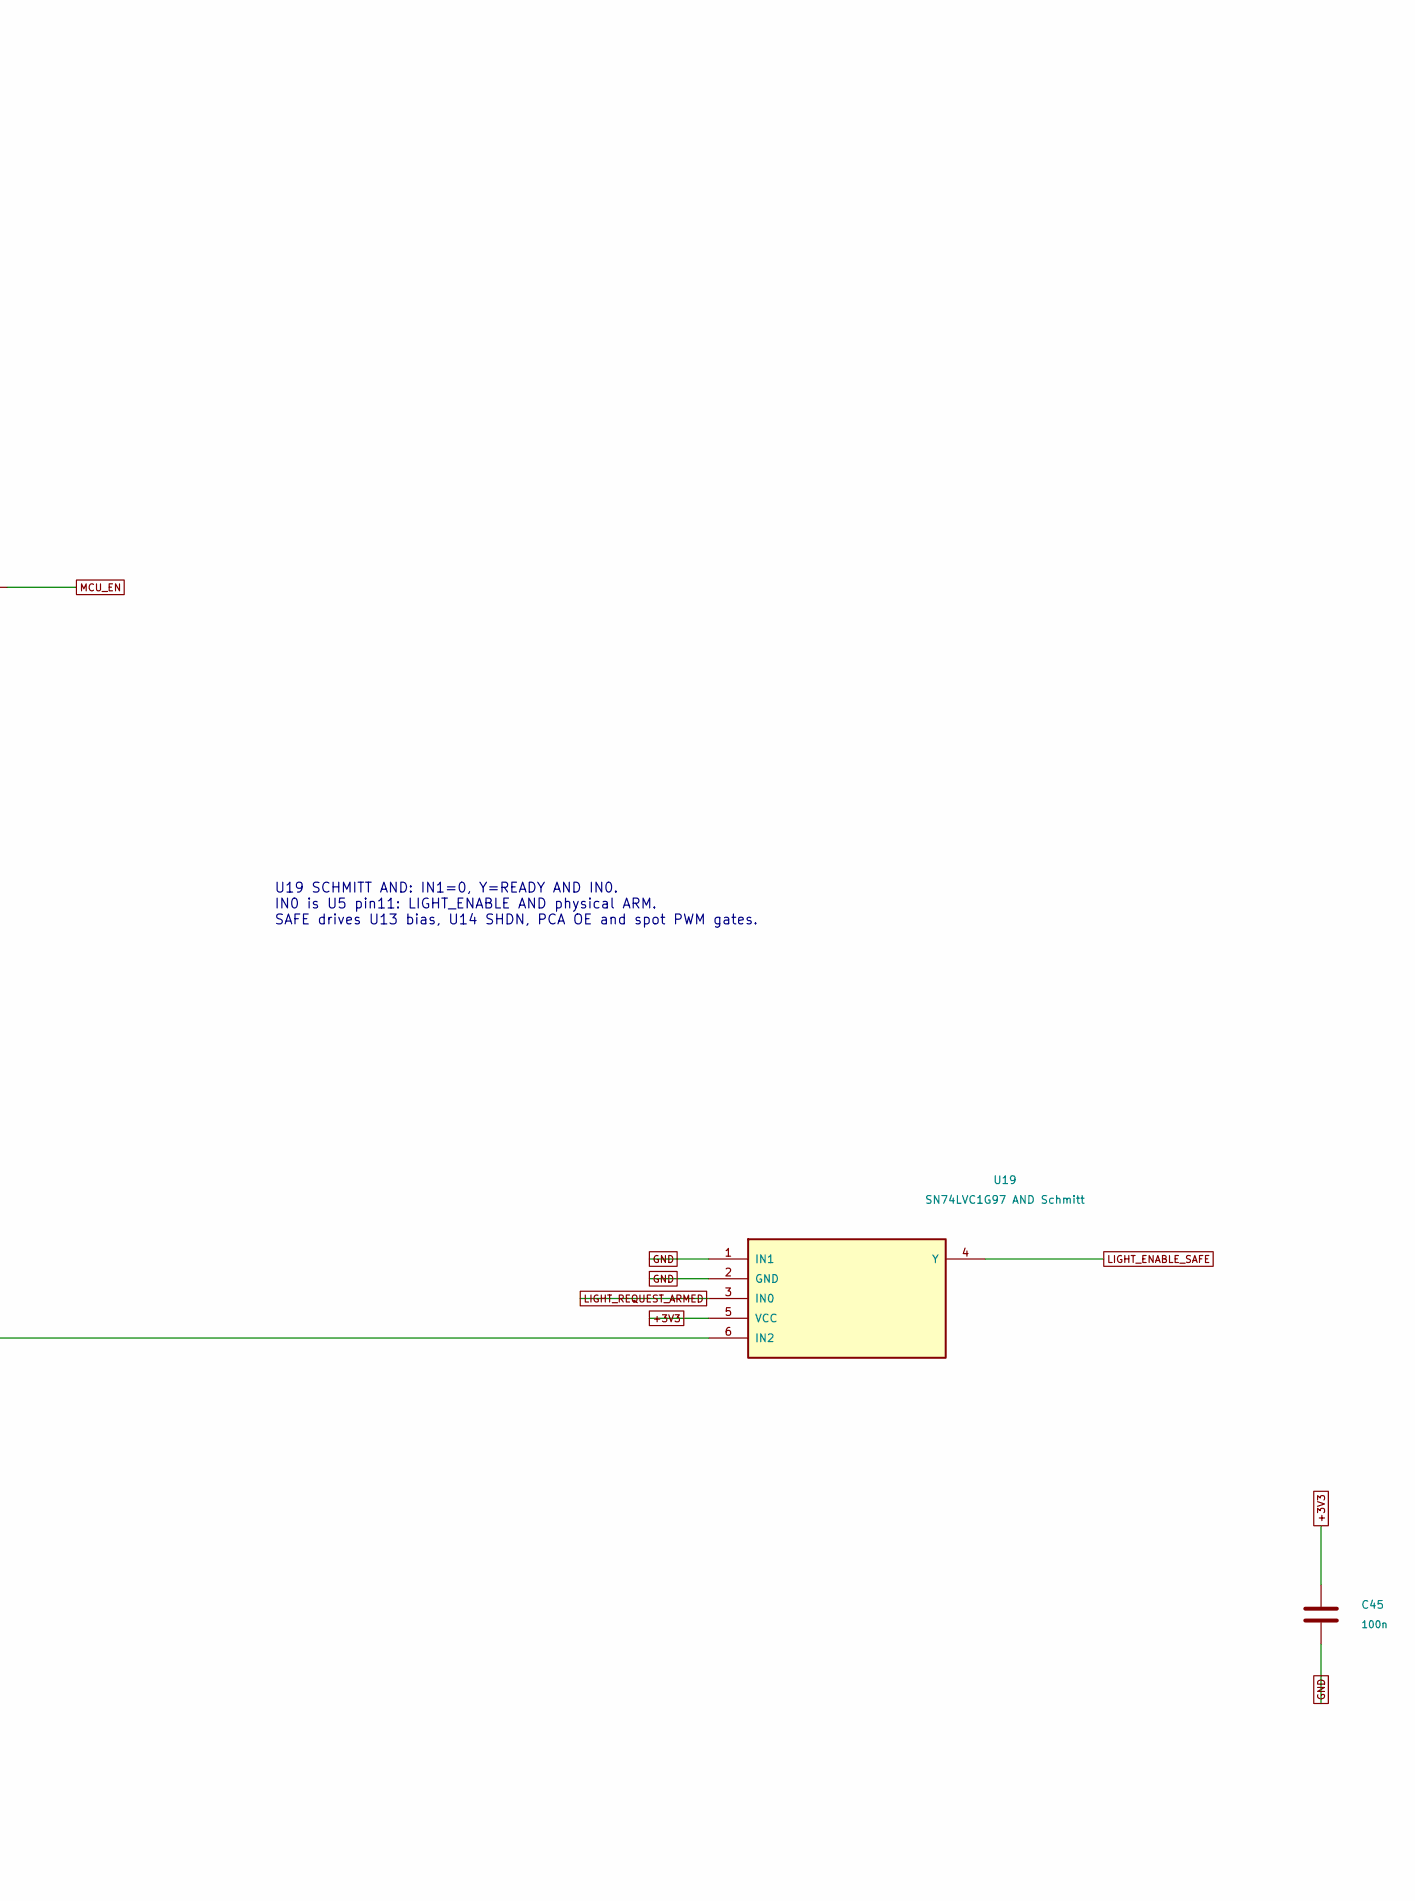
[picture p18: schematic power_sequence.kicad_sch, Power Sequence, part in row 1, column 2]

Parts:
C44, C45: 100n; C_0603_1608Metric; MPN GRM188R72A104KA35D
R42: 1k; R_0603_1608Metric; MPN RC0603FR-071KL
U18: TPS3808G33; SOT-23-6_FabPin1; MPN TPS3808G33DBVR
U19: SN74LVC1G97 AND Schmitt; SOT-23-6; MPN SN74LVC1G97DBVR

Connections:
+3V3: C44.1, C45.1, U18.3 (MR_N), U18.5 (SENSE), U18.6 (VDD), U19.5 (VCC); also elsewhere on the board
GND: C44.2, C45.2, U18.2 (GND), U19.1 (IN1), U19.2 (GND); also elsewhere on the board
LIGHT_ENABLE_SAFE: U19.4 (Y); also elsewhere on the board
LIGHT_REQUEST_ARMED: U19.3 (IN0); also elsewhere on the board
MCU_EN: R42.2; also elsewhere on the board
READY_3V3: R42.1, U18.1 (RESET_N), U19.6 (IN2); also elsewhere on the board

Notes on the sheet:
POWER SEQUENCE
SUPPLY QUALIFICATION / HARDWARE LIGHTING INHIBIT
U18 monitors +3V3: 3.07 V nominal falling threshold. CT intentionally open: 12-28 ms reset release delay. R42 limits discharge from existing MCU_EN capacitor C1. MCU_EN pullup R1, capacitor C1 and manual S1 are on controller.
U19 SCHMITT AND: IN1=0, Y=READY AND IN0. IN0 is U5 pin11: LIGHT_ENABLE AND physical ARM. SAFE drives U13 bias, U14 SHDN, PCA OE and spot PWM gates.
READY also feeds USB R41/R39; independent of ARM. Prototype timing and 0<V3V3<1.65 V behavior require measurement. After reset: initialize outputs OFF, verify PCA state, require fresh enable.

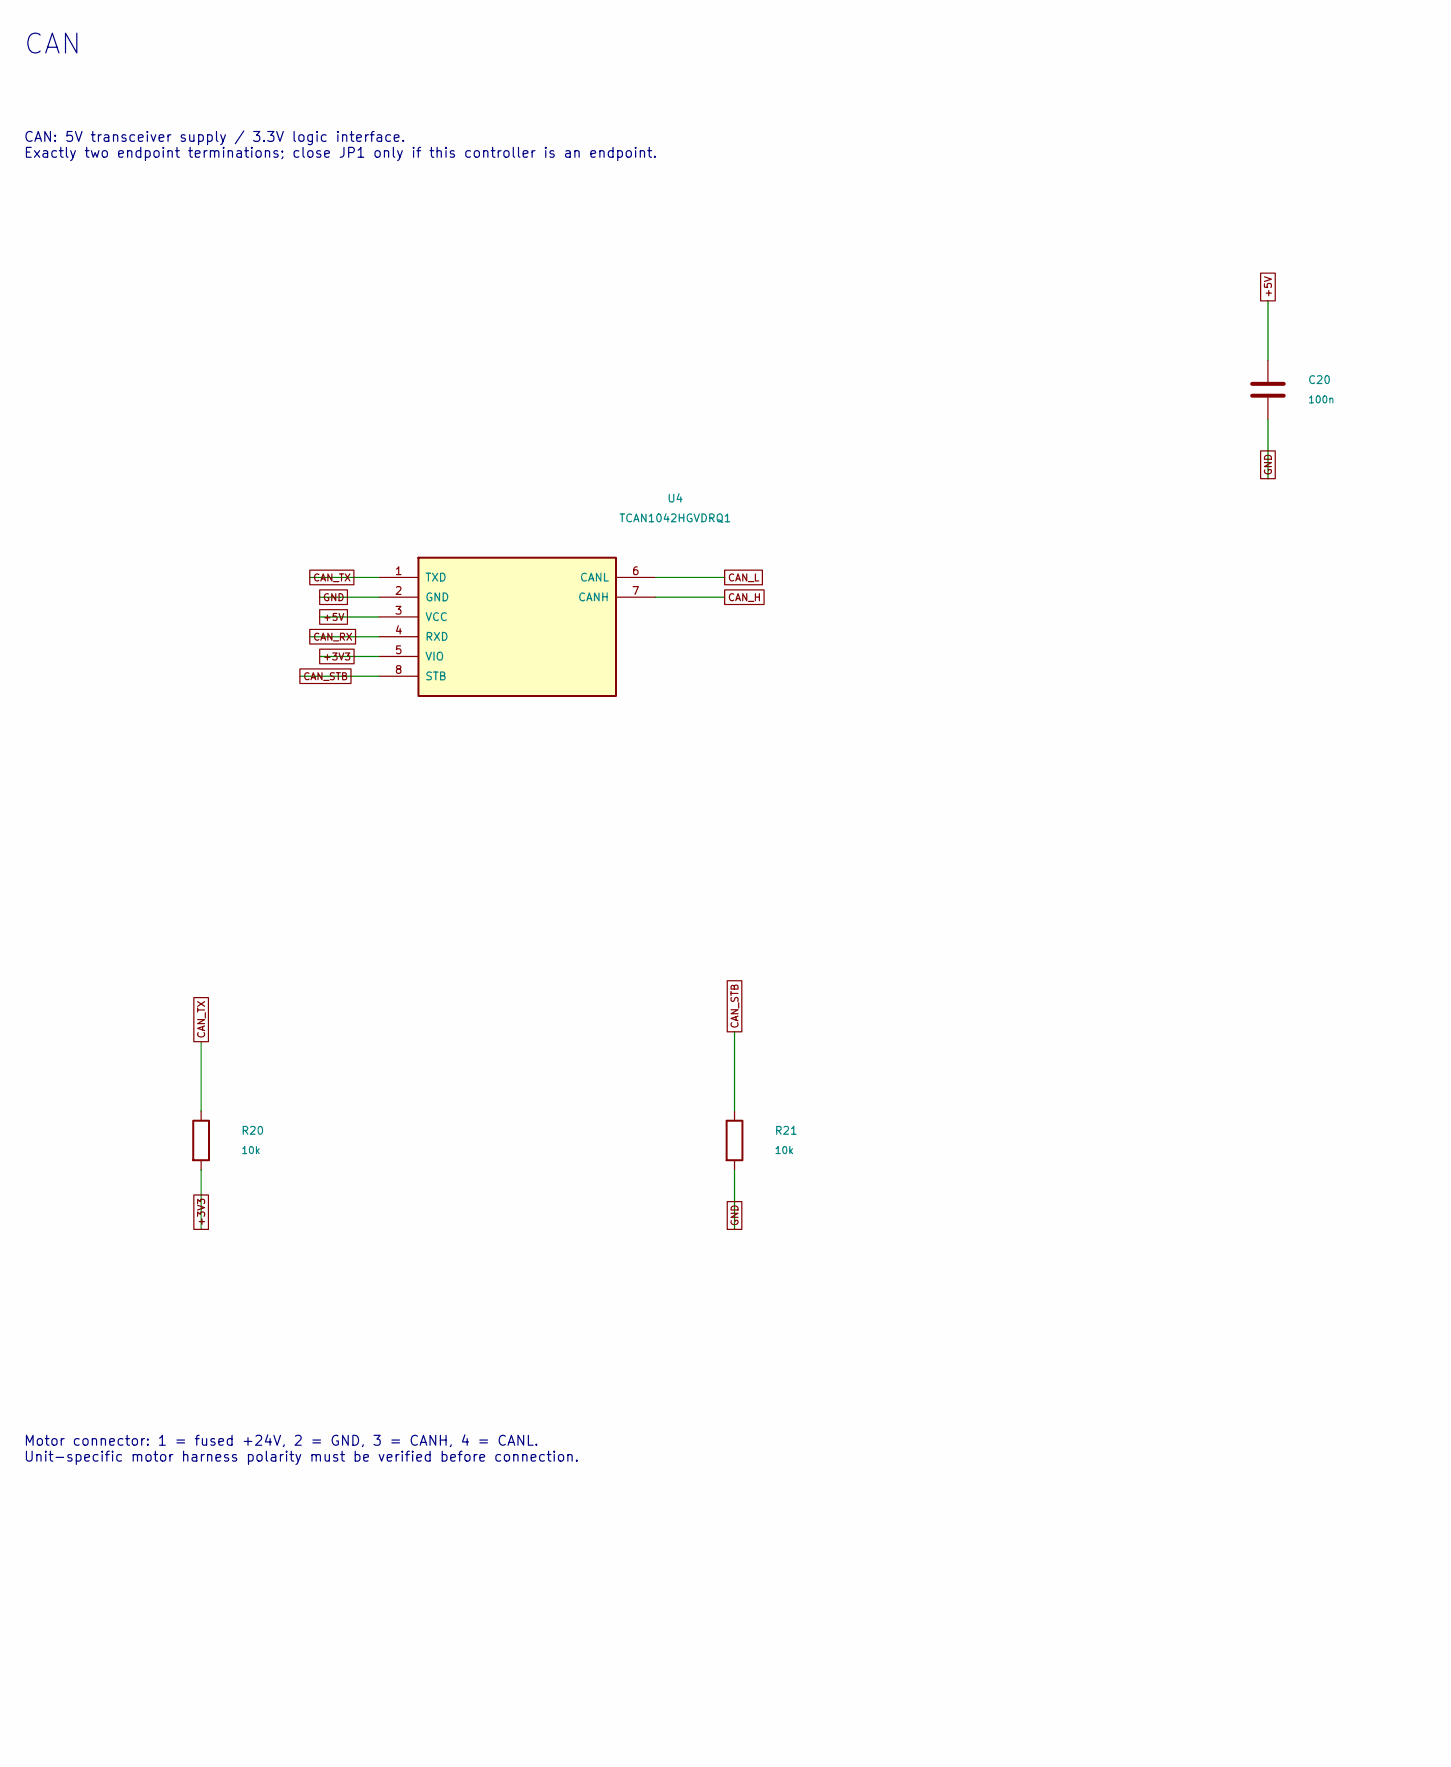
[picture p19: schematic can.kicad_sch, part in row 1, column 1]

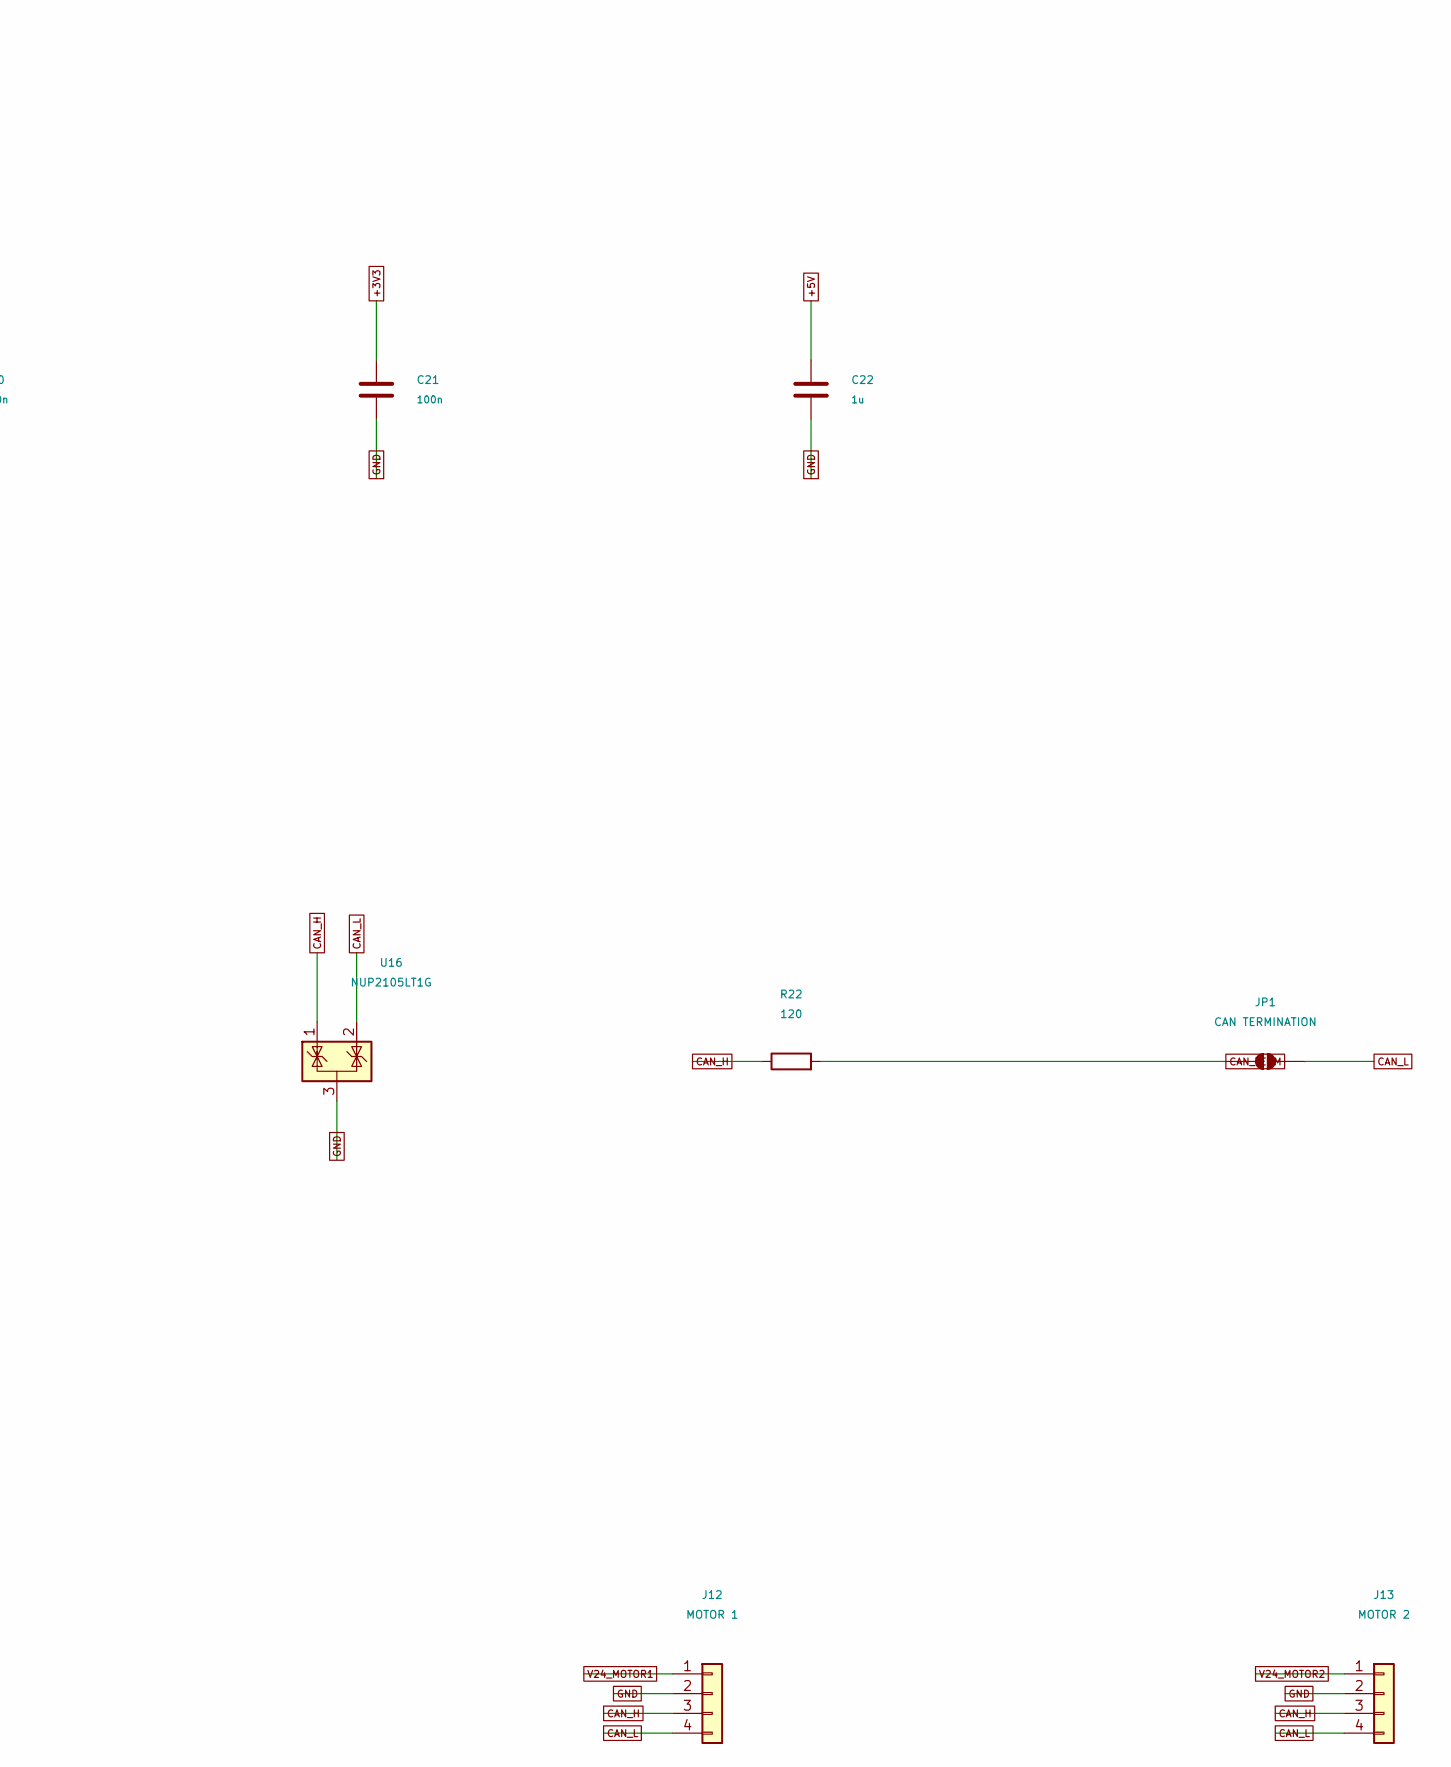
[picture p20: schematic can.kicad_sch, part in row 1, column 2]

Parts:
C20, C21: 100n; C_0603_1608Metric; MPN GRM188R72A104KA35D
C22: 1u; C_0603_1608Metric; MPN C1608X7R1E105K080AB
J12: MOTOR 1; JST_PA_BM04B_PASS_TFT_1x04_P2mm_Vertical; MPN BM04B-PASS-TFT(LF)(SN)
J13: MOTOR 2; JST_PA_BM04B_PASS_TFT_1x04_P2mm_Vertical; MPN BM04B-PASS-TFT(LF)(SN)
JP1: CAN TERMINATION; SolderJumper-2_P1.3mm_Open_RoundedPad1.0x1.5mm
R20, R21: 10k; R_0603_1608Metric; MPN RC0603FR-0710KL
R22: 120; R_0805_2012Metric; MPN RC0805FR-07120RL
U4: TCAN1042HGVDRQ1; SOIC-8_3.9x4.9mm_P1.27mm; MPN TCAN1042HGVDRQ1
U16: NUP2105LT1G; SOT-23; MPN NUP2105LT1G

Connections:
+3V3: C21.1, R20.2, U4.5 (VIO); also elsewhere on the board
+5V: C20.1, C22.1, U4.3 (VCC); also elsewhere on the board
CAN_H: J12.3, J13.3, R22.1, U4.7 (CANH), U16.1 (K)
CAN_L: J12.4, J13.4, JP1.2 (B), U4.6 (CANL), U16.2 (K)
CAN_RX: U4.4 (RXD); also elsewhere on the board
CAN_STB: R21.1, U4.8 (STB)
CAN_TERM: JP1.1 (A), R22.2
CAN_TX: R20.1, U4.1 (TXD); also elsewhere on the board
GND: C20.2, C21.2, C22.2, J12.2, J13.2, R21.2, U4.2 (GND), U16.3 (A); also elsewhere on the board
V24_MOTOR1: J12.1; also elsewhere on the board
V24_MOTOR2: J13.1; also elsewhere on the board

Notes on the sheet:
CAN
CAN: 5V transceiver supply / 3.3V logic interface. Exactly two endpoint terminations; close JP1 only if this controller is an endpoint.
Motor connector: 1 = fused +24V, 2 = GND, 3 = CANH, 4 = CANL. Unit-specific motor harness polarity must be verified before connection.

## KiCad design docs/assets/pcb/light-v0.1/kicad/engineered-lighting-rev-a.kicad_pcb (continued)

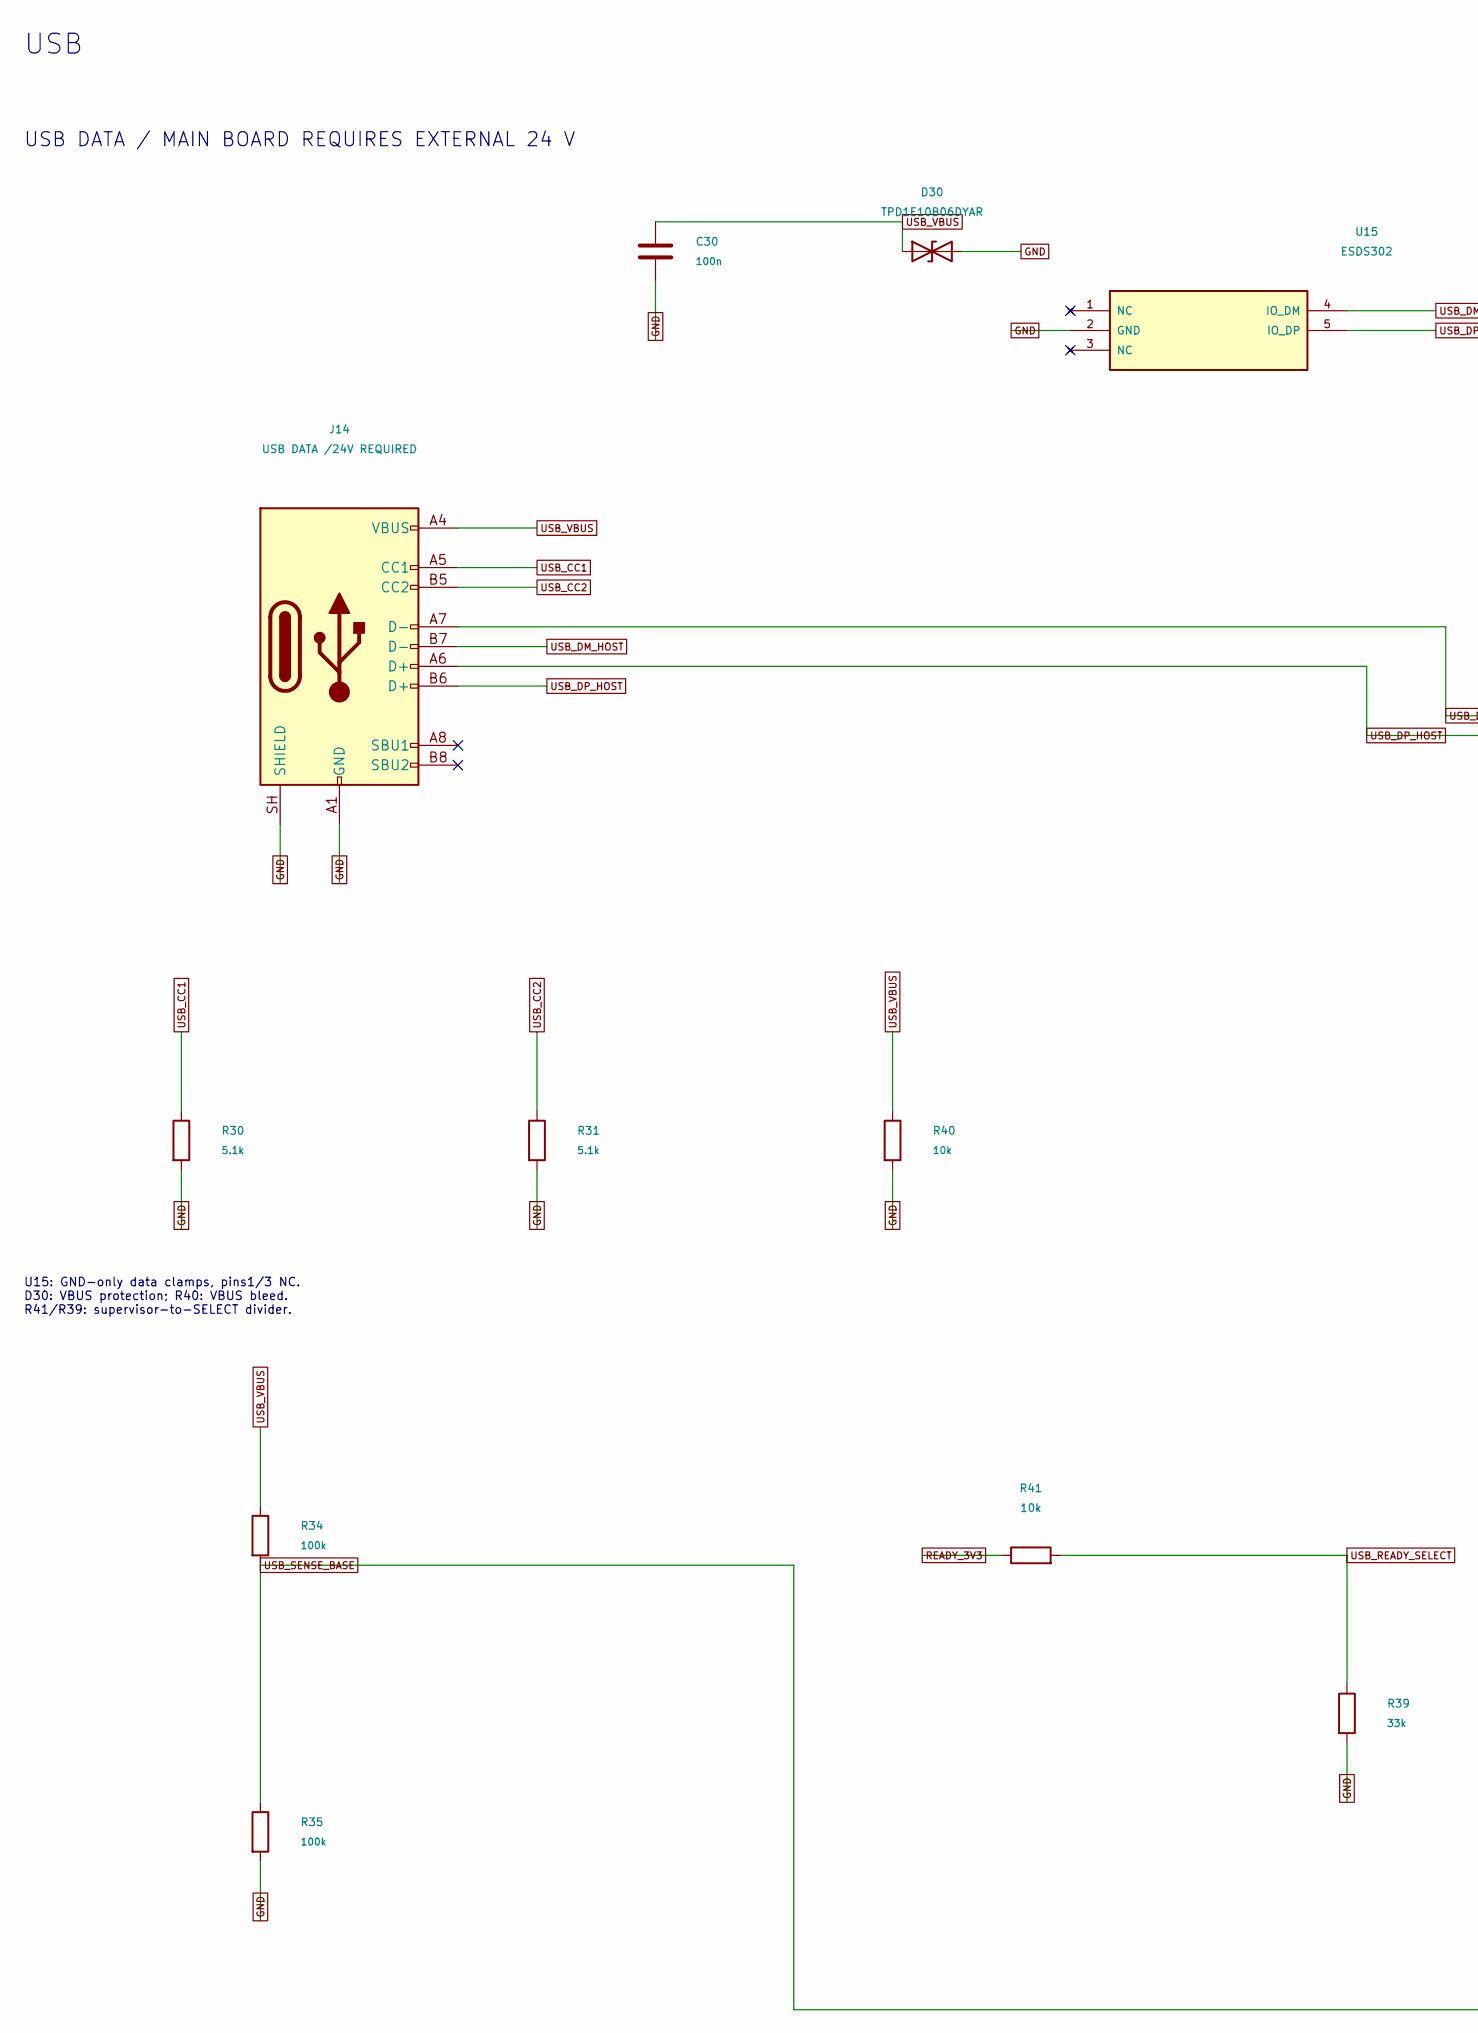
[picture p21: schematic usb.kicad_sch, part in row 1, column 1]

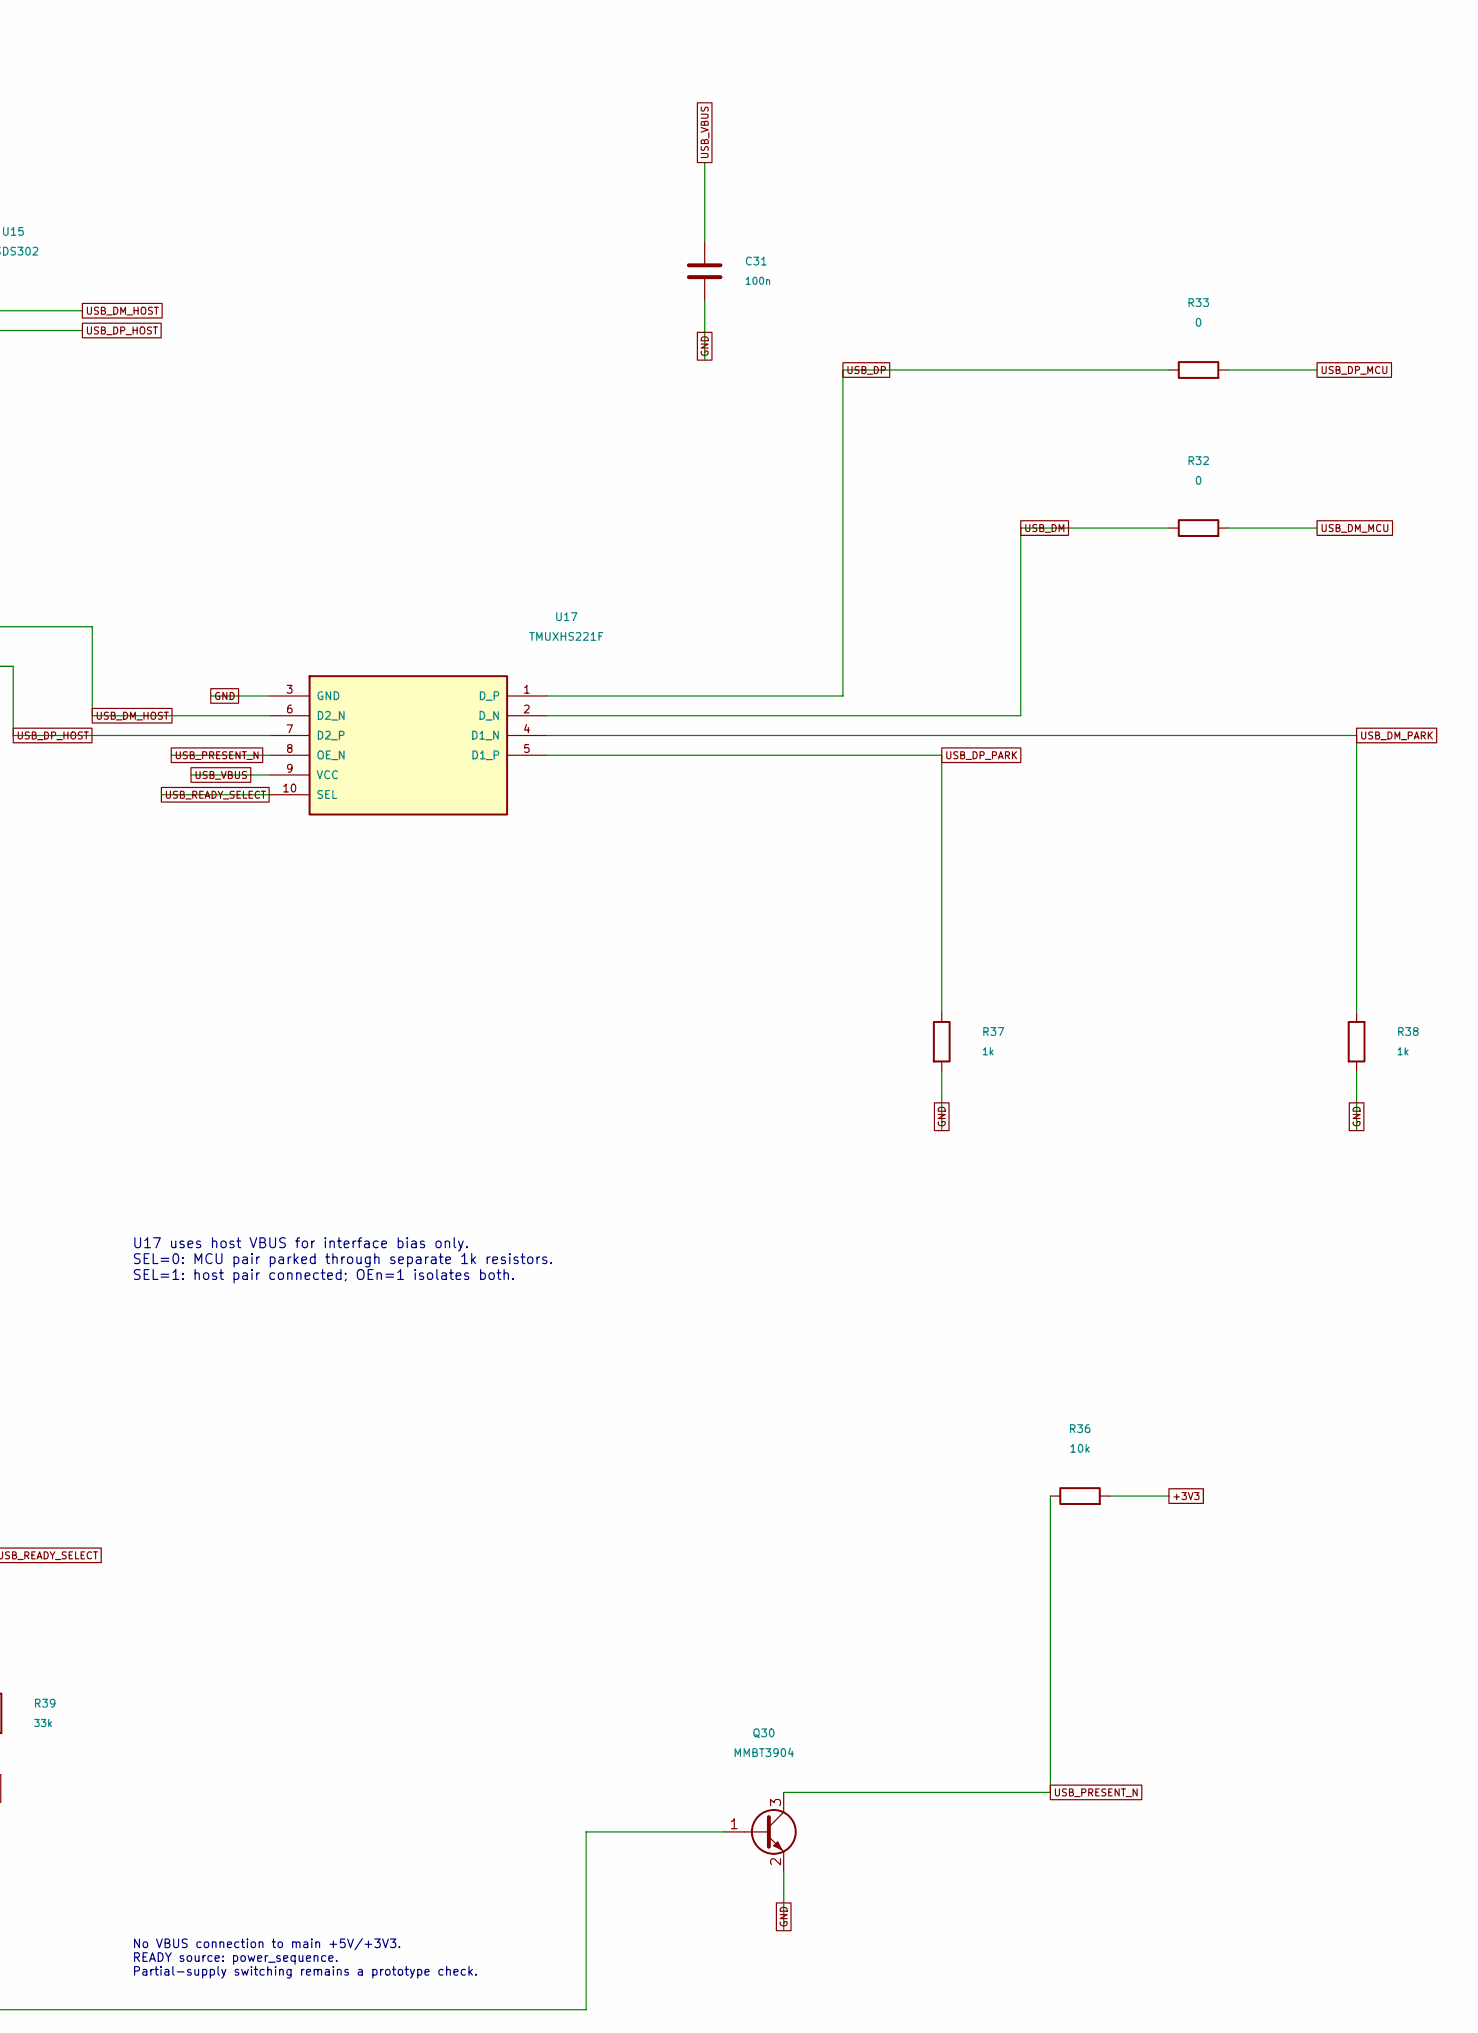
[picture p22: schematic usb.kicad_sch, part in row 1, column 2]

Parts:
C30, C31: 100n; C_0603_1608Metric; MPN GRM188R72A104KA35D
D30: TPD1E10B06DYAR; D_SOD-523; MPN TPD1E10B06DYAR
J14: USB DATA /24V REQUIRED; USB_C_Receptacle_GCT_USB4105-xx-A_16P_TopMnt_Horizontal; MPN USB4105-GF-A
Q30: MMBT3904; SOT-23; MPN MMBT3904-7-F
R30, R31: 5.1k; R_0603_1608Metric; MPN RC0603FR-075K1L
R32, R33: 0; R_0603_1608Metric; MPN RC0603JR-070RL
R34, R35: 100k; R_0603_1608Metric; MPN RC0603FR-07100KL
R36, R40, R41: 10k; R_0603_1608Metric; MPN RC0603FR-0710KL
R37, R38: 1k; R_0603_1608Metric; MPN RC0603FR-071KL
R39: 33k; R_0603_1608Metric; MPN RC0603FR-0733KL
U15: ESDS302; SOT-23-5; MPN ESDS302DBVR
U17: TMUXHS221F; TI_RSW0010A_UQFN10_1p4x1p8_TMUXHS221F; MPN TMUXHS221FRSWR

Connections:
+3V3: R36.2; also elsewhere on the board
GND: C30.2, C31.2, D30.2 (A2), J14.A1 (GND), J14.A12 (GND), J14.B1 (GND), J14.B12 (GND), J14.SH (SHIELD), Q30.2 (E), R30.2, R31.2, R35.2, R37.2, R38.2, R39.2, R40.2, U15.2 (GND), U17.3 (GND); also elsewhere on the board
READY_3V3: R41.1; also elsewhere on the board
USB_CC1: J14.A5 (CC1), R30.1
USB_CC2: J14.B5 (CC2), R31.1
USB_DM: R32.1, U17.2 (D_N)
USB_DM_HOST: J14.A7 (D-), J14.B7 (D-), U15.4 (IO_DM), U17.6 (D2_N)
USB_DM_MCU: R32.2; also elsewhere on the board
USB_DM_PARK: R38.1, U17.4 (D1_N)
USB_DP: R33.1, U17.1 (D_P)
USB_DP_HOST: J14.A6 (D+), J14.B6 (D+), U15.5 (IO_DP), U17.7 (D2_P)
USB_DP_MCU: R33.2; also elsewhere on the board
USB_DP_PARK: R37.1, U17.5 (D1_P)
USB_PRESENT_N: Q30.3 (C), R36.1, U17.8 (OE_N); also elsewhere on the board
USB_READY_SELECT: R39.1, R41.2, U17.10 (SEL)
USB_SENSE_BASE: Q30.1 (B), R34.2, R35.1
USB_VBUS: C30.1, C31.1, D30.1 (A1), J14.A4 (VBUS), J14.A9 (VBUS), J14.B4 (VBUS), J14.B9 (VBUS), R34.1, R40.1, U17.9 (VCC)

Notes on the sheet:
USB
USB DATA / MAIN BOARD REQUIRES EXTERNAL 24 V
U17 uses host VBUS for interface bias only. SEL=0: MCU pair parked through separate 1k resistors. SEL=1: host pair connected; OEn=1 isolates both.
U15: GND-only data clamps, pins1/3 NC. D30: VBUS protection; R40: VBUS bleed. R41/R39: supervisor-to-SELECT divider.
No VBUS connection to main +5V/+3V3. READY source: power_sequence. Partial-supply switching remains a prototype check.

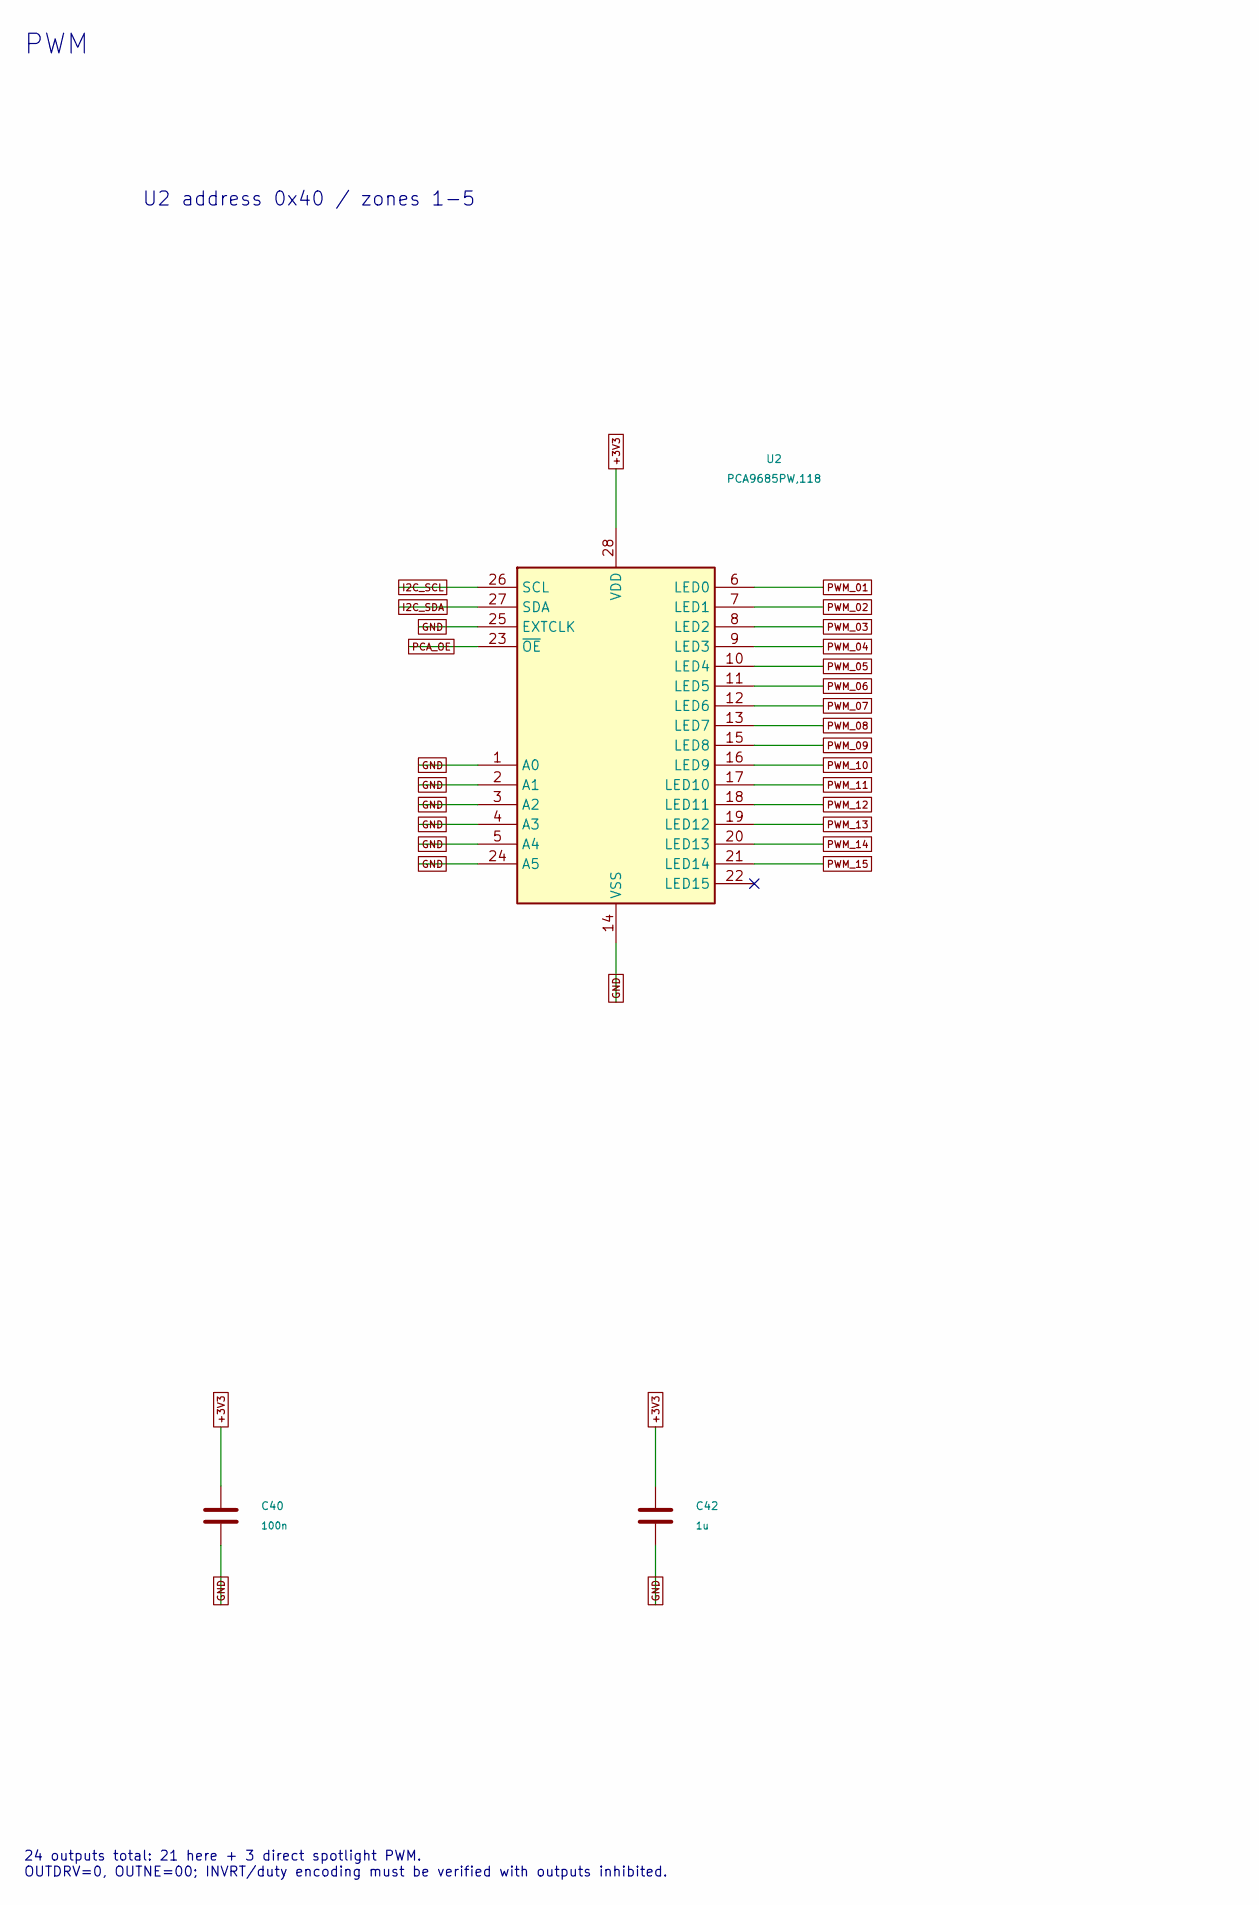
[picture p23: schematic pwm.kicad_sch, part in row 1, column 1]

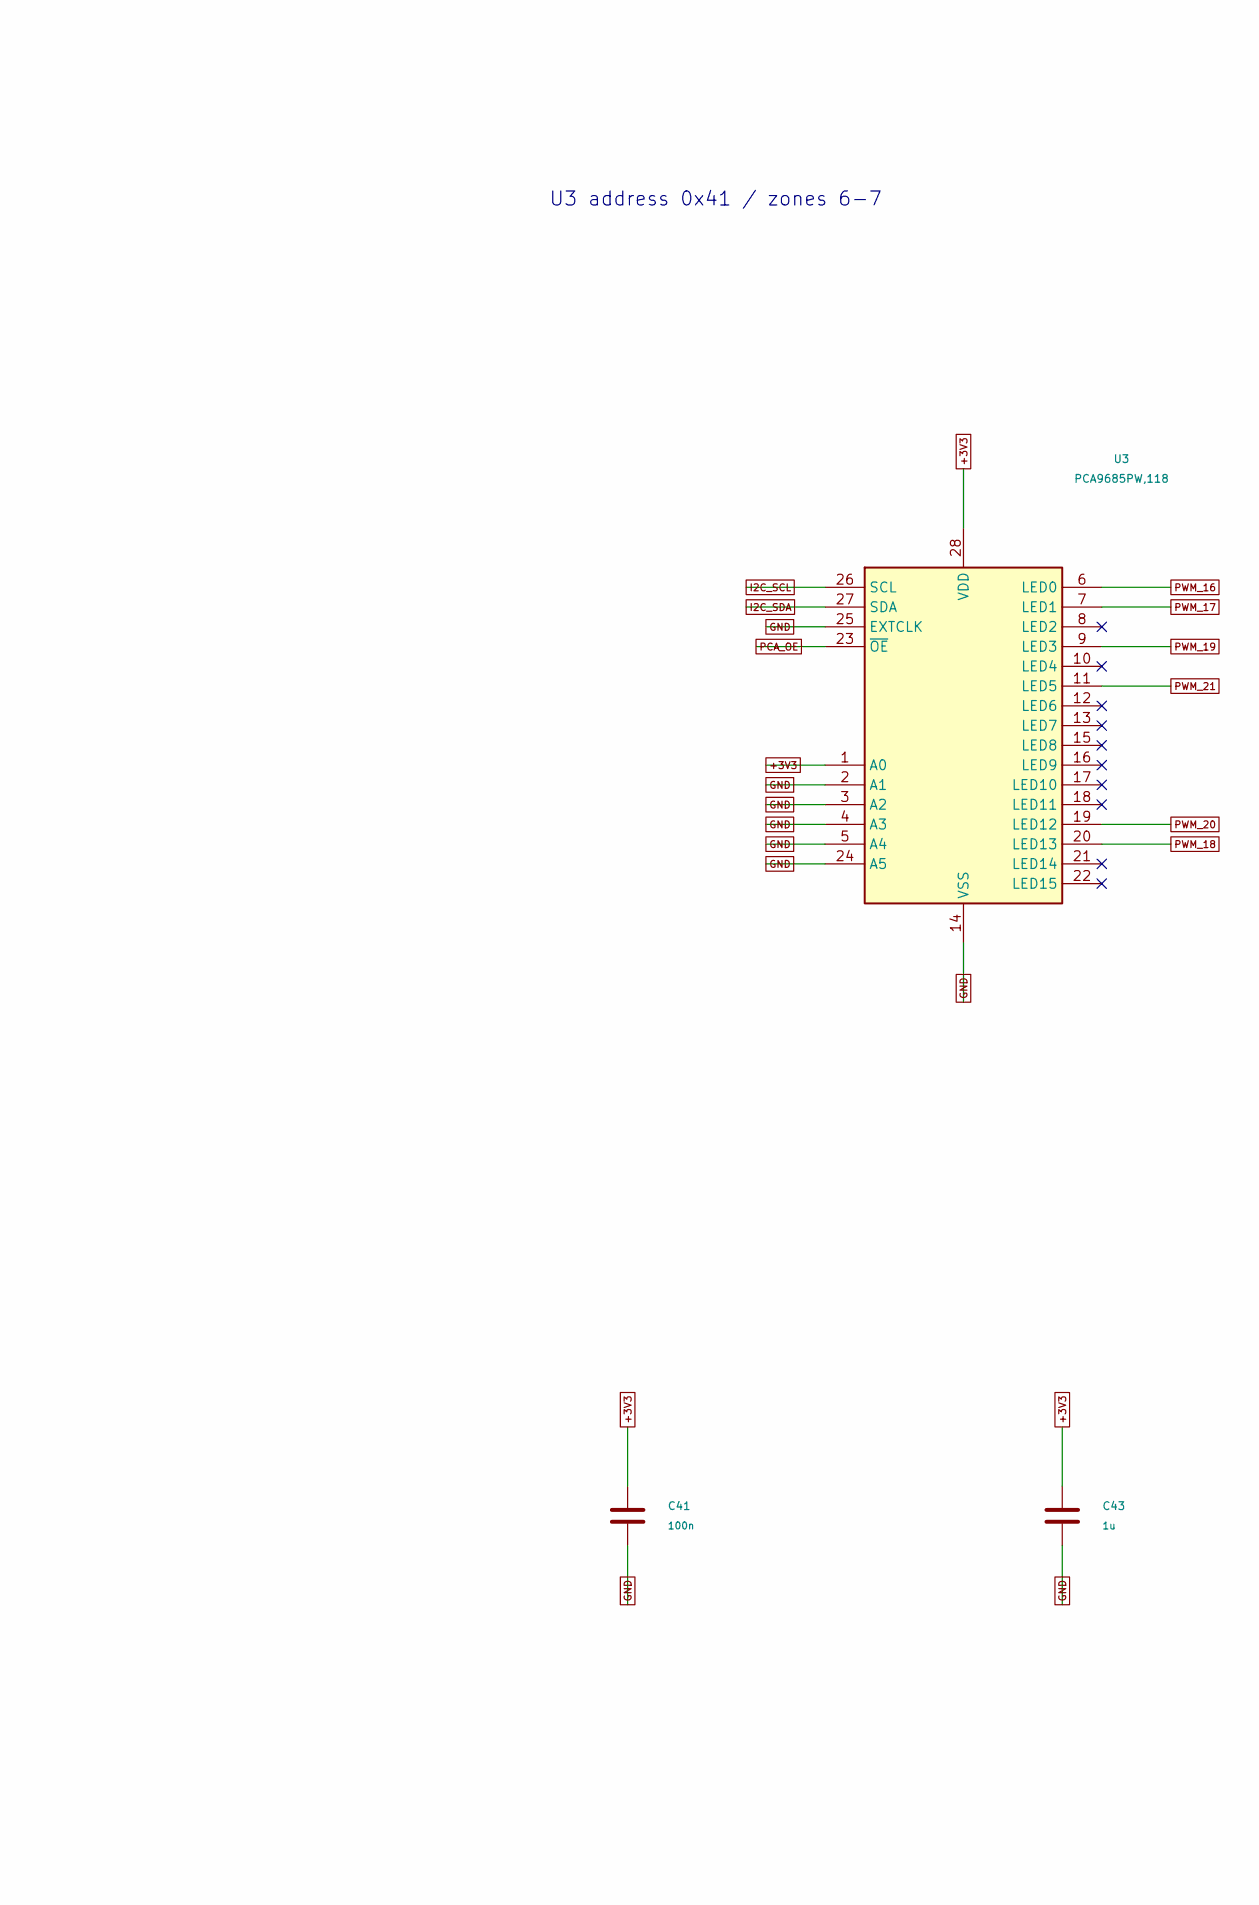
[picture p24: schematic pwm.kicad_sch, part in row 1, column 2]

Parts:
C40, C41: 100n; C_0603_1608Metric; MPN GRM188R72A104KA35D
C42, C43: 1u; C_0603_1608Metric; MPN C1608X7R1E105K080AB
U2, U3: PCA9685PW,118; TSSOP-28_4.4x9.7mm_P0.65mm; MPN PCA9685PW,118

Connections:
+3V3: C40.1, C41.1, C42.1, C43.1, U2.28 (VDD), U3.1 (A0), U3.28 (VDD); also elsewhere on the board
GND: C40.2, C41.2, C42.2, C43.2, U2.1 (A0), U2.2 (A1), U2.3 (A2), U2.4 (A3), U2.5 (A4), U2.14 (VSS), U2.24 (A5), U2.25 (EXTCLK), U3.2 (A1), U3.3 (A2), U3.4 (A3), U3.5 (A4), U3.14 (VSS), U3.24 (A5), U3.25 (EXTCLK); also elsewhere on the board
I2C_SCL: U2.26 (SCL), U3.26 (SCL); also elsewhere on the board
I2C_SDA: U2.27 (SDA), U3.27 (SDA); also elsewhere on the board
PCA_OE: U2.23 (~OE), U3.23 (~OE); also elsewhere on the board
PWM_01: U2.6 (LED0); also elsewhere on the board
PWM_02: U2.7 (LED1); also elsewhere on the board
PWM_03: U2.8 (LED2); also elsewhere on the board
PWM_04: U2.9 (LED3); also elsewhere on the board
PWM_05: U2.10 (LED4); also elsewhere on the board
PWM_06: U2.11 (LED5); also elsewhere on the board
PWM_07: U2.12 (LED6); also elsewhere on the board
PWM_08: U2.13 (LED7); also elsewhere on the board
PWM_09: U2.15 (LED8); also elsewhere on the board
PWM_10: U2.16 (LED9); also elsewhere on the board
PWM_11: U2.17 (LED10); also elsewhere on the board
PWM_12: U2.18 (LED11); also elsewhere on the board
PWM_13: U2.19 (LED12); also elsewhere on the board
PWM_14: U2.20 (LED13); also elsewhere on the board
PWM_15: U2.21 (LED14); also elsewhere on the board
PWM_16: U3.6 (LED0); also elsewhere on the board
PWM_17: U3.7 (LED1); also elsewhere on the board
PWM_18: U3.20 (LED13); also elsewhere on the board
PWM_19: U3.9 (LED3); also elsewhere on the board
PWM_20: U3.19 (LED12); also elsewhere on the board
PWM_21: U3.11 (LED5); also elsewhere on the board

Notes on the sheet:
PWM
U2 address 0x40 / zones 1-5
U3 address 0x41 / zones 6-7
24 outputs total: 21 here + 3 direct spotlight PWM. OUTDRV=0, OUTNE=00; INVRT/duty encoding must be verified with outputs inhibited.

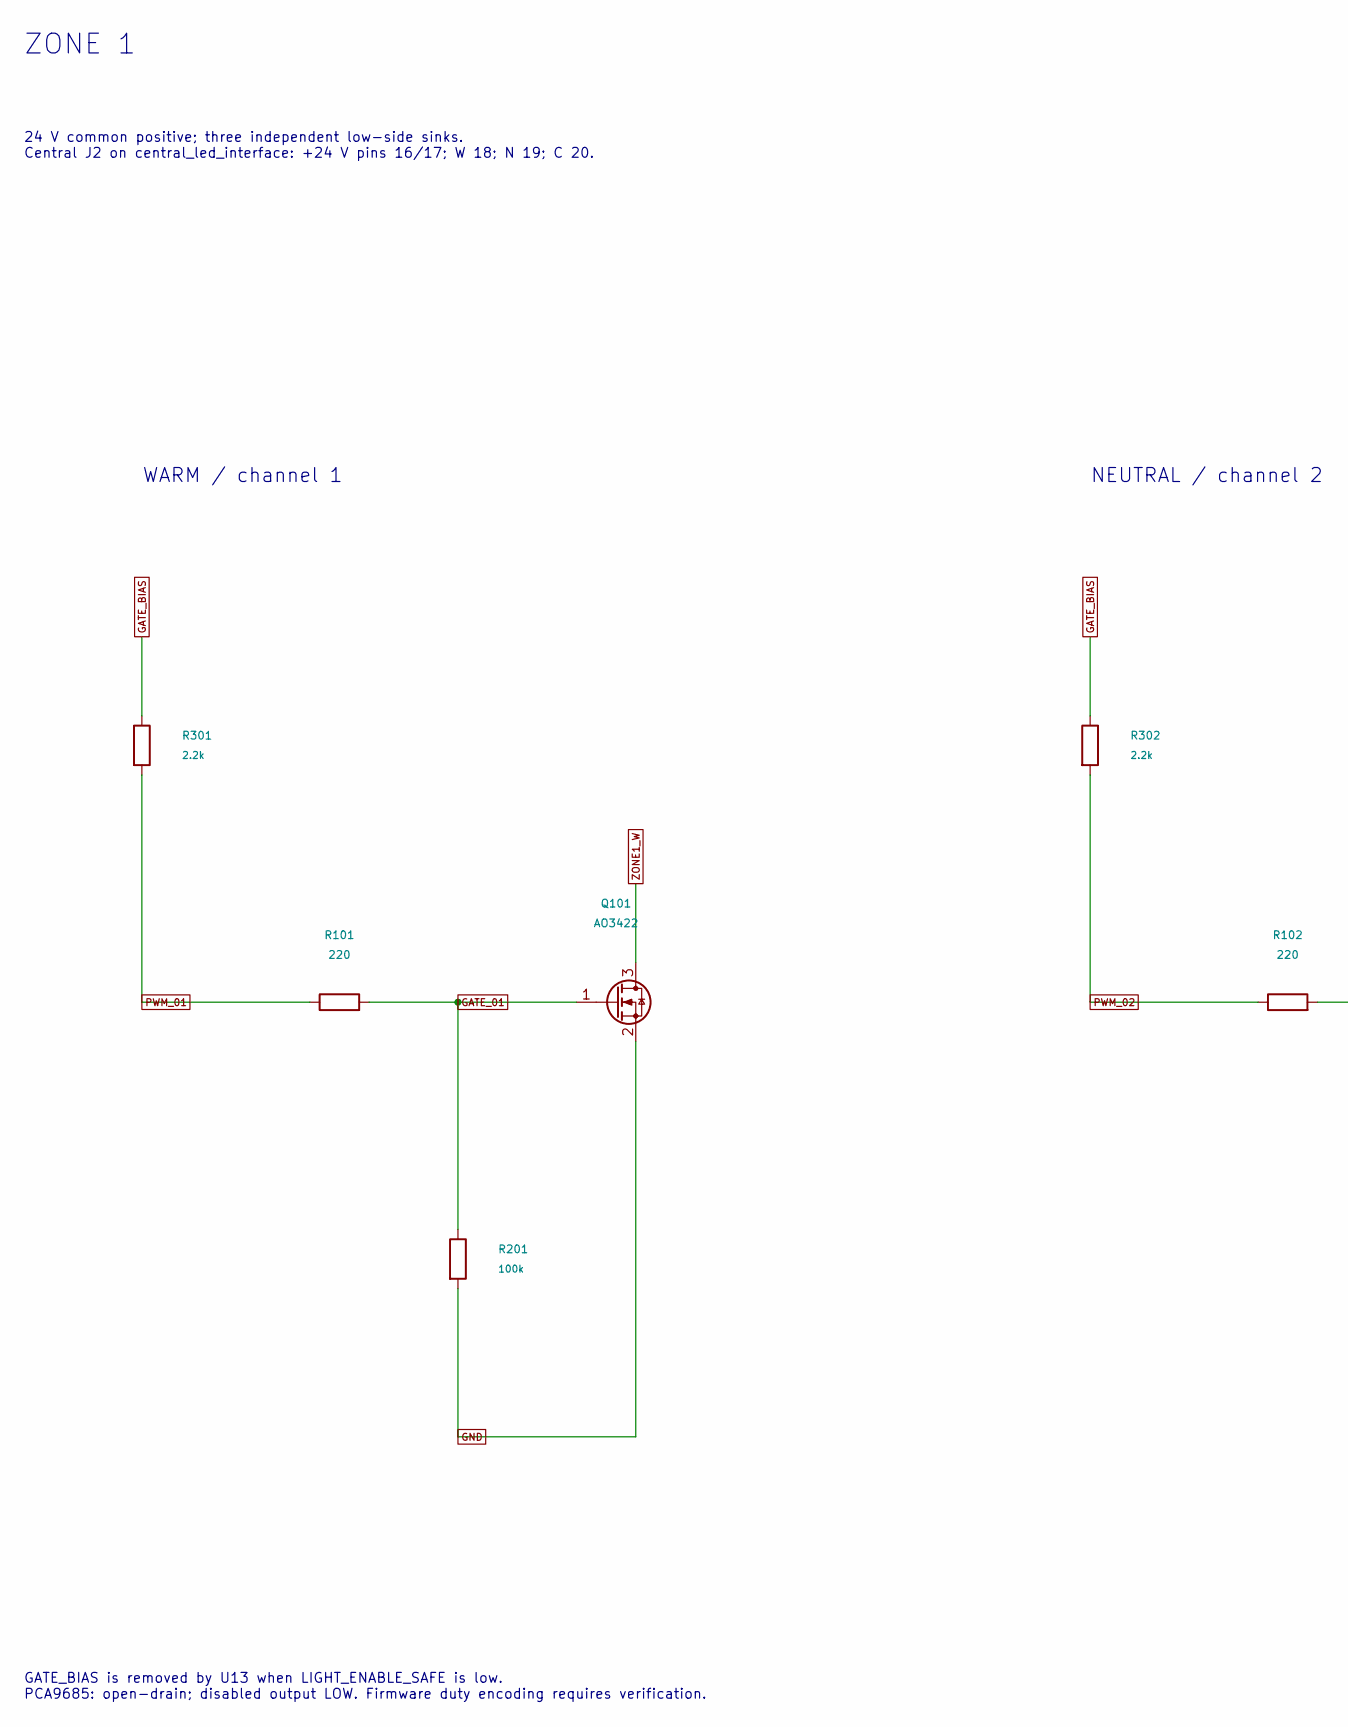
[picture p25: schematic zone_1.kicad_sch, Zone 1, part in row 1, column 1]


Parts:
Q101, Q102, Q103: AO3422; SOT-23; MPN AO3422
R101, R102, R103: 220; R_0603_1608Metric; MPN RC0603FR-07220RL
R201, R202, R203: 100k; R_0603_1608Metric; MPN RC0603FR-07100KL
R301, R302, R303: 2.2k; R_0603_1608Metric; MPN RC0603FR-072K2L

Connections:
GATE_01: Q101.1 (G), R101.2, R201.1
GATE_02: Q102.1 (G), R102.2, R202.1
GATE_03: Q103.1 (G), R103.2, R203.1
GATE_BIAS: R301.1, R302.1, R303.1; also elsewhere on the board
GND: Q101.2 (S), Q102.2 (S), Q103.2 (S), R201.2, R202.2, R203.2; also elsewhere on the board
PWM_01: R101.1, R301.2; also elsewhere on the board
PWM_02: R102.1, R302.2; also elsewhere on the board
PWM_03: R103.1, R303.2; also elsewhere on the board
ZONE1_C: Q103.3 (D); also elsewhere on the board
ZONE1_N: Q102.3 (D); also elsewhere on the board
ZONE1_W: Q101.3 (D); also elsewhere on the board

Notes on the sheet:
ZONE 1
24 V common positive; three independent low-side sinks. Central J2 on central_led_interface: +24 V pins 16/17; W 18; N 19; C 20.
WARM / channel 1
NEUTRAL / channel 2
COOL / channel 3
GATE_BIAS is removed by U13 when LIGHT_ENABLE_SAFE is low. PCA9685: open-drain; disabled output LOW. Firmware duty encoding requires verification.

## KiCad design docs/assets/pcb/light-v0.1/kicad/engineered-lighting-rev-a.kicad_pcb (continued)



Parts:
Q104, Q105, Q106: AO3422; SOT-23; MPN AO3422
R104, R105, R106: 220; R_0603_1608Metric; MPN RC0603FR-07220RL
R204, R205, R206: 100k; R_0603_1608Metric; MPN RC0603FR-07100KL
R304, R305, R306: 2.2k; R_0603_1608Metric; MPN RC0603FR-072K2L

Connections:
GATE_04: Q104.1 (G), R104.2, R204.1
GATE_05: Q105.1 (G), R105.2, R205.1
GATE_06: Q106.1 (G), R106.2, R206.1
GATE_BIAS: R304.1, R305.1, R306.1; also elsewhere on the board
GND: Q104.2 (S), Q105.2 (S), Q106.2 (S), R204.2, R205.2, R206.2; also elsewhere on the board
PWM_04: R104.1, R304.2; also elsewhere on the board
PWM_05: R105.1, R305.2; also elsewhere on the board
PWM_06: R106.1, R306.2; also elsewhere on the board
ZONE2_C: Q106.3 (D); also elsewhere on the board
ZONE2_N: Q105.3 (D); also elsewhere on the board
ZONE2_W: Q104.3 (D); also elsewhere on the board

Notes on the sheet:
ZONE 2
24 V common positive; three independent low-side sinks. Central J2 on central_led_interface: +24 V pins 21/22; W 23; N 24; C 25.
WARM / channel 4
NEUTRAL / channel 5
COOL / channel 6
GATE_BIAS is removed by U13 when LIGHT_ENABLE_SAFE is low. PCA9685: open-drain; disabled output LOW. Firmware duty encoding requires verification.

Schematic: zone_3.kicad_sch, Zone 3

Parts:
Q107, Q108, Q109: AO3422; SOT-23; MPN AO3422
R107, R108, R109: 220; R_0603_1608Metric; MPN RC0603FR-07220RL
R207, R208, R209: 100k; R_0603_1608Metric; MPN RC0603FR-07100KL
R307, R308, R309: 2.2k; R_0603_1608Metric; MPN RC0603FR-072K2L

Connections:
GATE_07: Q107.1 (G), R107.2, R207.1
GATE_08: Q108.1 (G), R108.2, R208.1
GATE_09: Q109.1 (G), R109.2, R209.1
GATE_BIAS: R307.1, R308.1, R309.1; also elsewhere on the board
GND: Q107.2 (S), Q108.2 (S), Q109.2 (S), R207.2, R208.2, R209.2; also elsewhere on the board
PWM_07: R107.1, R307.2; also elsewhere on the board
PWM_08: R108.1, R308.2; also elsewhere on the board
PWM_09: R109.1, R309.2; also elsewhere on the board
ZONE3_C: Q109.3 (D); also elsewhere on the board
ZONE3_N: Q108.3 (D); also elsewhere on the board
ZONE3_W: Q107.3 (D); also elsewhere on the board

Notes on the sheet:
ZONE 3
24 V common positive; three independent low-side sinks. Central J2 on central_led_interface: +24 V pins 26/27; W 28; N 29; C 30.
WARM / channel 7
NEUTRAL / channel 8
COOL / channel 9
GATE_BIAS is removed by U13 when LIGHT_ENABLE_SAFE is low. PCA9685: open-drain; disabled output LOW. Firmware duty encoding requires verification.

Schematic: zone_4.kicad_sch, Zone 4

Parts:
Q110, Q111, Q112: AO3422; SOT-23; MPN AO3422
R110, R111, R112: 220; R_0603_1608Metric; MPN RC0603FR-07220RL
R210, R211, R212: 100k; R_0603_1608Metric; MPN RC0603FR-07100KL
R310, R311, R312: 2.2k; R_0603_1608Metric; MPN RC0603FR-072K2L

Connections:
GATE_10: Q110.1 (G), R110.2, R210.1
GATE_11: Q111.1 (G), R111.2, R211.1
GATE_12: Q112.1 (G), R112.2, R212.1
GATE_BIAS: R310.1, R311.1, R312.1; also elsewhere on the board
GND: Q110.2 (S), Q111.2 (S), Q112.2 (S), R210.2, R211.2, R212.2; also elsewhere on the board
PWM_10: R110.1, R310.2; also elsewhere on the board
PWM_11: R111.1, R311.2; also elsewhere on the board
PWM_12: R112.1, R312.2; also elsewhere on the board
ZONE4_C: Q112.3 (D); also elsewhere on the board
ZONE4_N: Q111.3 (D); also elsewhere on the board
ZONE4_W: Q110.3 (D); also elsewhere on the board

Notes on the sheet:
ZONE 4
24 V common positive; three independent low-side sinks. Central J2 on central_led_interface: +24 V pins 1/2; W 3; N 4; C 5.
WARM / channel 10
NEUTRAL / channel 11
COOL / channel 12
GATE_BIAS is removed by U13 when LIGHT_ENABLE_SAFE is low. PCA9685: open-drain; disabled output LOW. Firmware duty encoding requires verification.

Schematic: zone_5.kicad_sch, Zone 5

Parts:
Q113, Q114, Q115: AO3422; SOT-23; MPN AO3422
R113, R114, R115: 220; R_0603_1608Metric; MPN RC0603FR-07220RL
R213, R214, R215: 100k; R_0603_1608Metric; MPN RC0603FR-07100KL
R313, R314, R315: 2.2k; R_0603_1608Metric; MPN RC0603FR-072K2L

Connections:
GATE_13: Q113.1 (G), R113.2, R213.1
GATE_14: Q114.1 (G), R114.2, R214.1
GATE_15: Q115.1 (G), R115.2, R215.1
GATE_BIAS: R313.1, R314.1, R315.1; also elsewhere on the board
GND: Q113.2 (S), Q114.2 (S), Q115.2 (S), R213.2, R214.2, R215.2; also elsewhere on the board
PWM_13: R113.1, R313.2; also elsewhere on the board
PWM_14: R114.1, R314.2; also elsewhere on the board
PWM_15: R115.1, R315.2; also elsewhere on the board
ZONE5_C: Q115.3 (D); also elsewhere on the board
ZONE5_N: Q114.3 (D); also elsewhere on the board
ZONE5_W: Q113.3 (D); also elsewhere on the board

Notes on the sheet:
ZONE 5
24 V common positive; three independent low-side sinks. Central J2 on central_led_interface: +24 V pins 6/7; W 8; N 9; C 10.
WARM / channel 13
NEUTRAL / channel 14
COOL / channel 15
GATE_BIAS is removed by U13 when LIGHT_ENABLE_SAFE is low. PCA9685: open-drain; disabled output LOW. Firmware duty encoding requires verification.

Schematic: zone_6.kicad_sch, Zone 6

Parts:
Q116, Q117, Q118: AO3422; SOT-23; MPN AO3422
R116, R117, R118: 220; R_0603_1608Metric; MPN RC0603FR-07220RL
R216, R217, R218: 100k; R_0603_1608Metric; MPN RC0603FR-07100KL
R316, R317, R318: 2.2k; R_0603_1608Metric; MPN RC0603FR-072K2L

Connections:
GATE_16: Q116.1 (G), R116.2, R216.1
GATE_17: Q117.1 (G), R117.2, R217.1
GATE_18: Q118.1 (G), R118.2, R218.1
GATE_BIAS: R316.1, R317.1, R318.1; also elsewhere on the board
GND: Q116.2 (S), Q117.2 (S), Q118.2 (S), R216.2, R217.2, R218.2; also elsewhere on the board
PWM_16: R116.1, R316.2; also elsewhere on the board
PWM_17: R117.1, R317.2; also elsewhere on the board
PWM_18: R118.1, R318.2; also elsewhere on the board
ZONE6_C: Q118.3 (D); also elsewhere on the board
ZONE6_N: Q117.3 (D); also elsewhere on the board
ZONE6_W: Q116.3 (D); also elsewhere on the board

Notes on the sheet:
ZONE 6
24 V common positive; three independent low-side sinks. Central J2 on central_led_interface: +24 V pins 11/12; W 13; N 14; C 15.
WARM / channel 16
NEUTRAL / channel 17
COOL / channel 18
GATE_BIAS is removed by U13 when LIGHT_ENABLE_SAFE is low. PCA9685: open-drain; disabled output LOW. Firmware duty encoding requires verification.

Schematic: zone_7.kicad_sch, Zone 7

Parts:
J8: ZONE 7; JST_GH_BM04B-GHS-TBT_1x04-1MP_P1.25mm_Vertical; MPN BM04B-GHS-TBT(LF)(SN)
Q119, Q120, Q121: AO3422; SOT-23; MPN AO3422
R119, R120, R121: 220; R_0603_1608Metric; MPN RC0603FR-07220RL
R219, R220, R221: 100k; R_0603_1608Metric; MPN RC0603FR-07100KL
R319, R320, R321: 2.2k; R_0603_1608Metric; MPN RC0603FR-072K2L

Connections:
GATE_19: Q119.1 (G), R119.2, R219.1
GATE_20: Q120.1 (G), R120.2, R220.1
GATE_21: Q121.1 (G), R121.2, R221.1
GATE_BIAS: R319.1, R320.1, R321.1; also elsewhere on the board
GND: Q119.2 (S), Q120.2 (S), Q121.2 (S), R219.2, R220.2, R221.2; also elsewhere on the board
PWM_19: R119.1, R319.2; also elsewhere on the board
PWM_20: R120.1, R320.2; also elsewhere on the board
PWM_21: R121.1, R321.2; also elsewhere on the board
ZONE7_24V: J8.1; also elsewhere on the board
ZONE7_C: J8.4, Q121.3 (D)
ZONE7_N: J8.3, Q120.3 (D)
ZONE7_W: J8.2, Q119.3 (D)

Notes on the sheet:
ZONE 7
24 V common positive; three independent low-side sinks. Connector poles: 1 = fused +24 V, 2 = W, 3 = N, 4 = C.
WARM / channel 19
NEUTRAL / channel 20
COOL / channel 21
GATE_BIAS is removed by U13 when LIGHT_ENABLE_SAFE is low. PCA9685: open-drain; disabled output LOW. Firmware duty encoding requires verification.

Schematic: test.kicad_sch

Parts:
TP1: GND; TestPoint_Pad_D1.0mm; not fitted
TP2: VIN24_RAW; TestPoint_Pad_D1mm_NoComponentCourtyard; not fitted
TP3: V24_BUS; TestPoint_Pad_D1.0mm; not fitted
TP4: +5V; TestPoint_Pad_D1.0mm; not fitted
TP5: +3V3; TestPoint_Pad_D1.0mm; not fitted
TP6: GATE_BIAS; TestPoint_Pad_D1.0mm; not fitted
TP7: LIGHT_ENABLE_SAFE; TestPoint_Pad_D1.0mm; not fitted
TP8: EFUSE_RESET_N; TestPoint_Pad_D1.0mm; not fitted
TP9: V24_SPOT; TestPoint_Pad_D1.0mm; not fitted
TP10: I2C_SDA; TestPoint_Pad_D1.0mm; not fitted
TP11: I2C_SCL; TestPoint_Pad_D1.0mm; not fitted
TP12: PCA_OE; TestPoint_Pad_D1.0mm; not fitted

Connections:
+3V3: TP5.1; also elsewhere on the board
+5V: TP4.1; also elsewhere on the board
EFUSE_RESET_N: TP8.1; also elsewhere on the board
GATE_BIAS: TP6.1; also elsewhere on the board
GND: TP1.1; also elsewhere on the board
I2C_SCL: TP11.1; also elsewhere on the board
I2C_SDA: TP10.1; also elsewhere on the board
LIGHT_ENABLE_SAFE: TP7.1; also elsewhere on the board
PCA_OE: TP12.1; also elsewhere on the board
V24_BUS: TP3.1; also elsewhere on the board
V24_SPOT: TP9.1; also elsewhere on the board
VIN24_RAW: TP2.1; also elsewhere on the board

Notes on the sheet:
TEST
COPPER TEST POINTS / POWER-FLAG ANNOTATIONS Physical ARM must remain open during first power checks.

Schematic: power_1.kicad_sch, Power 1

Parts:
C500, C502, C503, C505: 100nF 100V X7R; C_0603_1608Metric; MPN GRM188R72A104KA35D
C501: 1uF 100V X7R; C_1206_3216Metric; MPN C3216X7R2A105K160AA
C504: 1000uF 50V low ESR; CP_CDE_AFK_CaseP_D16_H17_Provisional; MPN AFK108M50P44T-F
D500: SMBJ33CA 33V bidirectional TVS; D_SMB; MPN SMBJ33CA
F1: 6.3A backup fuse; Enclosure_F1; MPN 045106.3MRL
F2, F3: 1A motor branch fuse; Fuse_Littelfuse-NANO2-451_453; MPN 0451001.MRL
F4, F5, F6, F7, F8, F9, F10: 0.75A ambient zone fuse; Fuse_Littelfuse-NANO2-451_453; MPN 0451.750MRL
F11: 0.5A logic branch fuse; Fuse_Littelfuse-NANO2-451_453; MPN 0451.500MRL
Q500: 100V reverse blocking MOSFET; VSON-8_3.3x3.3mm_P0.65mm_NexFET; MPN CSD19537Q3
Q501: fast reverse gate pull-down; SOT-23; MPN 2N7002BK,215
R500: 4.02k; R_0603_1608Metric; MPN RC0603FR-074K02L
R501: 140k; R_0603_1608Metric; MPN RC0603FR-07140KL
R502, R504, R506, R507, R508, R509: 10k; R_0603_1608Metric; MPN RC0603FR-0710KL
R503: 210k; R_0603_1608Metric; MPN RC0603FR-07210KL
R505: 165k; R_0603_1608Metric; MPN RC0603FR-07165KL
U12: 24V input eFuse / 4.5A nominal; Texas_RGE0024H_VQFN-24-1EP_4x4mm_P0.5mm_EP2.7x2.7mm_Thermal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; MPN TPS26630RGER

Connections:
+3V3: R508.1, R509.1; also elsewhere on the board
EFUSE_BGATE: Q500.4 (G), Q501.3 (D), U12.3 (BGATE)
EFUSE_DRV: Q501.1 (G), U12.4 (DRV)
EFUSE_DVDT: C503.1, U12.9 (dVdt)
EFUSE_FLT_N: R508.2, U12.14 (FLT)
EFUSE_ILIM: R500.1, U12.10 (ILIM)
EFUSE_IMON: R507.1, U12.13 (IMON)
EFUSE_OVP: R503.2, R504.1, U12.7 (OVP)
EFUSE_PGOOD: R509.2, U12.16 (PGOOD)
EFUSE_PGTH: R505.2, R506.1, U12.15 (PGTH)
EFUSE_RESET_N: U12.12 (SHDN_internal_pullup); also elsewhere on the board
EFUSE_UVLO: R501.2, R502.1, U12.6 (UVLO)
GND: C500.2, C501.2, C502.2, C503.2, C504.2, C505.2, D500.2 (A2), R500.2, R502.2, R504.2, R506.2, R507.2, U12.8 (GND), U12.25 (GND_EP); also elsewhere on the board
V24_BUS: C504.1, C505.1, F2.1, F3.1, F4.1, F5.1, F6.1, F7.1, F8.1, F9.1, F10.1, F11.1, R505.1, U12.17 (OUT), U12.18 (OUT); also elsewhere on the board
V24_LOGIC: F11.2; also elsewhere on the board
V24_MOTOR1: F2.2; also elsewhere on the board
V24_MOTOR2: F3.2; also elsewhere on the board
VIN24_FUSED: C500.1, C501.1, D500.1 (A1), F1.2, Q500.1 (S), Q500.2 (S), Q500.3 (S), Q501.2 (S), R501.1, R503.1, U12.5 (IN_SYS)
VIN24_RAW: F1.1; also elsewhere on the board
VIN24_RPP: C502.1, Q500.5 (D), U12.1 (IN), U12.2 (IN)
ZONE1_24V: F4.2; also elsewhere on the board
ZONE2_24V: F5.2; also elsewhere on the board
ZONE3_24V: F6.2; also elsewhere on the board
ZONE4_24V: F7.2; also elsewhere on the board
ZONE5_24V: F8.2; also elsewhere on the board
ZONE6_24V: F9.2; also elsewhere on the board
ZONE7_24V: F10.2; also elsewhere on the board

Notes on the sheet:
POWER 1
INPUT / REVERSE PROTECTION / MAIN eFUSE
J1 is on power_2. TVS input return is GND. U12 nominal current limit 4.5 A; prototype operating target <= 4.0 A.
Threshold / status / startup components
FUSED DISTRIBUTION: motors / ambient zones / logic

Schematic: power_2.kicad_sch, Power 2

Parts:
C506: 10uF 50V X7R; C_1210_3225Metric; MPN GRM32ER71H106KA12L
C507: 220nF 50V X7R; C_0805_2012Metric; MPN C2012X7R1H224K125AA
C508: 1uF 25V X7R; C_0603_1608Metric; MPN C1608X7R1E105K080AB
C509, C514, C515: 100nF 100V X7R; C_0603_1608Metric; MPN GRM188R72A104KA35D
C510, C511, C512, C513: 22uF 25V X7R; C_1210_3225Metric; MPN GRM32ER71E226KE15L
D505: 60V 5A output negative transient Schottky; D_SMC; MPN B560C-13-F
J1: 24V INPUT; Enclosure_J1; MPN 1771091
J16: BRAKE / BUS; Enclosure_J16; MPN 2053380002
L500: 22uH 2.5A RMS 5.5A sat; L_Bourns_SRP7050TA; MPN SRP7050TA-220M
L501: 2.2uH 2.9A RMS 3A sat; L_Bourns-SRN4018; MPN SRN4018-2R2M
R510: 100k; R_0603_1608Metric; MPN RC0603FR-07100KL
R511: 24.9k; R_0603_1608Metric; MPN RC0603FR-0724K9L
R512, R513: 10k; R_0603_1608Metric; MPN RC0603FR-0710KL
R514: 4.7k; R_0603_1608Metric; MPN RC0603FR-074K7L
U10: 24V to 5V 1A buck; TI_DDA0008B_EP2.71x3.4_ThermalVias_125um; MPN LMR36510ADDAR
U11: 5V to 3.3V 1A fixed buck; Texas_DSG0008A_WSON-8-1EP_2x2mm_P0.5mm_EP0.9x1.6mm_ThermalV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; MPN TPS62162DSGR
U13: switched ambient gate bias; SOT-363_SC-70-6; MPN TPS22919DCKR
U501: 27V flat-clamp transient protector; WSON-6-1EP_2x2mm_P0.65mm_EP1x1.6mm_ThermalVias; MPN TVS2700DRVR

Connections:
+3V3: C513.1, C514.1, L501.2, R512.1, R513.1, U11.6 (VOS), U13.1 (VIN); also elsewhere on the board
+5V: C510.1, C511.1, C512.1, L500.2, R510.1, U11.2 (VIN), U11.3 (EN); also elsewhere on the board
BUCK3_PGOOD: R513.2, U11.8 (PG)
BUCK3_SW: L501.1, U11.7 (SW)
BUCK5_BOOT: C509.1, U10.7 (BOOT)
BUCK5_FB: R510.2, R511.1, U10.5 (FB)
BUCK5_PGOOD: R512.2, U10.4 (PG)
BUCK5_SW: C509.2, L500.1, U10.8 (SW)
BUCK5_VCC: C508.1, U10.6 (VCC)
GATE_BIAS: C515.1, U13.5 (QOD), U13.6 (VOUT); also elsewhere on the board
GND: C506.2, C507.2, C508.2, C510.2, C511.2, C512.2, C513.2, C514.2, C515.2, D505.2 (A), J1.2, J16.2, R511.2, R514.2, U10.1 (PGND), U10.9 (PAD), U11.1 (PGND), U11.4 (AGND), U11.5 (FB), U11.9 (PAD), U13.2 (GND), U501.1 (GND), U501.2 (GND), U501.3 (GND), U501.7 (GND); also elsewhere on the board
LIGHT_ENABLE_SAFE: R514.1, U13.3 (ON); also elsewhere on the board
V24_BUS: D505.1 (K), J16.1, U501.4 (IN), U501.5 (IN), U501.6 (IN); also elsewhere on the board
V24_LOGIC: C506.1, C507.1, U10.2 (VIN), U10.3 (EN); also elsewhere on the board
VIN24_RAW: J1.1; also elsewhere on the board

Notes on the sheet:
POWER 2
24 V -> 5 V / 1 A
5 V -> 3.3 V / 1 A
Ambient gate-bias inhibit
J1 input continues to F1 on power_1. U501 is a local BUS shunt clamp. J16 is the external brake/bus port.

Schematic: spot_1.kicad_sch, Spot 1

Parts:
C516: 47nF 50V X7R; C_0603_1608Metric; MPN C1608X7R1H473K080AA
C517, C518: 100nF 100V X7R; C_0603_1608Metric; MPN GRM188R72A104KA35D
C519, C520, C521, C522: 10uF 50V X7R; C_1210_3225Metric; MPN GRM32ER71H106KA12L
D501: 60V output negative transient Schottky; D_SMA; MPN B160-13-F
D502, D503: 60V 1A flyback Schottky; D_SMA; MPN B160-13-F
L502, L503, L504: 220uH +/-20%, .6A RMS .7A saturation; L_Bourns_SRN6045; MPN SRN6045-221M
R515: 24.3k; R_0603_1608Metric; MPN RC0603FR-0724K3L
R516: 402k; R_0603_1608Metric; MPN RC0603FR-07402KL
R517: 210k; R_0603_1608Metric; MPN RC0603FR-07210KL
R518, R519, R520: 10k; R_0603_1608Metric; MPN RC0603FR-0710KL
R521: 47k; R_0603_1608Metric; MPN RC0603FR-0747KL
R523, R524, R525: 0.300ohm 1% 0.125W; R_0805_2012Metric; MPN ERJ-6RQFR30V
R526, R527, R528: 910; R_0603_1608Metric; MPN RC0603FR-07910RL
U7, U8, U9: 333mA spotlight CC driver; TSOT-23-5; MPN AL8860WT-7
U14: spot branch gated eFuse 0.494A nominal; TI_PWP0016A_EP3.3x3.3_6ThermalVias_125um; MPN TPS26600PWPR

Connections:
+3V3: R520.1; also elsewhere on the board
GND: C517.2, C518.2, C519.2, C520.2, C521.2, C522.2, D501.2 (A), R521.2, R526.2, R527.2, R528.2, U7.2 (GND), U8.2 (GND), U9.2 (GND), U14.9 (GND); also elsewhere on the board
LIGHT_ENABLE_SAFE: U14.7 (SHDN); also elsewhere on the board
SPOT1_CTRL: R526.1, U7.3 (CTRL); also elsewhere on the board
SPOT1_LED_MINUS: L502.1; also elsewhere on the board
SPOT1_LED_PLUS: R523.2, U7.4 (SET); also elsewhere on the board
SPOT1_SW: D502.2 (A), L502.2, U7.1 (SW)
SPOT2_CTRL: R527.1, U8.3 (CTRL); also elsewhere on the board
SPOT2_LED_MINUS: L503.1; also elsewhere on the board
SPOT2_LED_PLUS: R524.2, U8.4 (SET); also elsewhere on the board
SPOT2_SW: D503.2 (A), L503.2, U8.1 (SW)
SPOT3_CTRL: R528.1, U9.3 (CTRL); also elsewhere on the board
SPOT3_LED_MINUS: L504.1; also elsewhere on the board
SPOT3_LED_PLUS: R525.2, U9.4 (SET); also elsewhere on the board
SPOT3_SW: L504.2, U9.1 (SW); also elsewhere on the board
SPOT_EFUSE_DVDT: C516.1, U14.12 (dVdt)
SPOT_EFUSE_FLT_N: R520.2, U14.14 (FLT)
SPOT_EFUSE_ILIM: R515.1, U14.11 (ILIM)
SPOT_EFUSE_IMON: R519.1, U14.10 (IMON)
SPOT_EFUSE_MODE: R516.1, U14.6 (MODE)
SPOT_EFUSE_OVP: R517.2, R518.1, U14.5 (OVP)
SPOT_RTN: C516.2, R515.2, R516.2, R518.2, R519.2, U14.3 (UVLO), U14.8 (RTN), U14.17 (RTN_EP)
V24_BUS: C517.1, R517.1, U14.1 (IN), U14.2 (IN); also elsewhere on the board
V24_SPOT: C518.1, C519.1, C520.1, C521.1, C522.1, D501.1 (K), D502.1 (K), D503.1 (K), R521.1, R523.1, R524.1, R525.1, U7.5 (VIN), U8.5 (VIN), U9.5 (VIN), U14.15 (OUT), U14.16 (OUT); also elsewhere on the board

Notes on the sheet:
SPOT 1
INDEPENDENT SPOT SUPPLY INHIBIT / 0.494 A NOMINAL
SPOT_RTN belongs to U14: do not join it to GND. Stored charge remains after inhibition.
SPOT 1 / 333 mA nominal
Paired LED output -> J9 pins 1/2 / spot_2
SPOT 2 / 333 mA nominal
Paired LED output -> J9 pins 3/4 / spot_2
SPOT 3 / 333 mA nominal
Paired LED output -> J9 pins 5/6 / spot_2
CH3 diode/input capacitors continue on spot_2.

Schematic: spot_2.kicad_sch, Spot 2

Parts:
C523, C524: 10uF 50V X7R; C_1210_3225Metric; MPN GRM32ER71H106KA12L
D504: 60V 1A flyback Schottky; D_SMA; MPN B160-13-F
J9: SPOTLIGHT 3 PAIRS; JST_GH_BM06B-GHS-TBT_1x06-1MP_P1.25mm_Vertical; MPN BM06B-GHS-TBT(LF)(SN)
U500: 27V flat-clamp transient protector; WSON-6-1EP_2x2mm_P0.65mm_EP1x1.6mm_ThermalVias; MPN TVS2700DRVR

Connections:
GND: C523.2, C524.2, U500.1 (GND), U500.2 (GND), U500.3 (GND), U500.7 (GND); also elsewhere on the board
SPOT1_LED_MINUS: J9.2; also elsewhere on the board
SPOT1_LED_PLUS: J9.1; also elsewhere on the board
SPOT2_LED_MINUS: J9.4; also elsewhere on the board
SPOT2_LED_PLUS: J9.3; also elsewhere on the board
SPOT3_LED_MINUS: J9.6; also elsewhere on the board
SPOT3_LED_PLUS: J9.5; also elsewhere on the board
SPOT3_SW: D504.2 (A); also elsewhere on the board
V24_SPOT: C523.1, C524.1, D504.1 (K), U500.4 (IN), U500.5 (IN), U500.6 (IN); also elsewhere on the board

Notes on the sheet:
SPOT 2
J9: 1/2 = SPOT1 +/-, 3/4 = SPOT2 +/-, 5/6 = SPOT3 +/-. All three LED pairs remain independent; LED- is not GND. The wire service loop reaches the static arm flex; J13 separately carries tilt power and CAN.
CH3 current loop continuation from U9 on spot_1
U500 local spotlight-rail shunt clamp. Pulse limits do not establish continuous braking.

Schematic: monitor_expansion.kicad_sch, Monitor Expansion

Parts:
C46: 100n; C_0603_1608Metric; MPN GRM188R72A104KA35D
H1, H2, H3, H4: M3 / 3.2mm NPTH; MountingHole_3.2mm_M3; MPN PCB FEATURE
J18: GPIO EXPANSION 3V3; Expansion_SolderPads_1x07_P1p27mm; MPN PCB FEATURE
TP13: GPIO4 STRAP; TestPoint_Pad_D1.0mm; MPN PCB FEATURE
TP14: GPIO5 STRAP; TestPoint_Pad_D1.0mm; MPN PCB FEATURE
TP15: GPIO15 STRAP; TestPoint_Pad_D1.0mm; MPN PCB FEATURE
U20: TMP112AIDRLR; SOT-563; MPN TMP112AIDRLR

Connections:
+3V3: C46.1, J18.1, U20.5 (V+); also elsewhere on the board
GND: C46.2, J18.2, U20.2 (GND), U20.4 (ADD0); also elsewhere on the board
GPIO4_STRAP: TP13.1; also elsewhere on the board
GPIO5_STRAP: TP14.1; also elsewhere on the board
GPIO15_STRAP: TP15.1; also elsewhere on the board
GPIO19: J18.3; also elsewhere on the board
GPIO20: J18.4; also elsewhere on the board
GPIO21: J18.5; also elsewhere on the board
GPIO22: J18.6; also elsewhere on the board
GPIO23: J18.7; also elsewhere on the board
I2C_SCL: U20.1 (SCL); also elsewhere on the board
I2C_SDA: U20.6 (SDA); also elsewhere on the board

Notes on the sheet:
MONITOR EXPANSION

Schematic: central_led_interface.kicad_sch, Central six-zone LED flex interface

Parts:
J2: 2005280300 / 6-ZONE FLEX; Molex_2005280300_30P_Central_LED; MPN 2005280300

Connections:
ZONE1_24V: J2.16, J2.17; also elsewhere on the board
ZONE1_C: J2.20; also elsewhere on the board
ZONE1_N: J2.19; also elsewhere on the board
ZONE1_W: J2.18; also elsewhere on the board
ZONE2_24V: J2.21, J2.22; also elsewhere on the board
ZONE2_C: J2.25; also elsewhere on the board
ZONE2_N: J2.24; also elsewhere on the board
ZONE2_W: J2.23; also elsewhere on the board
ZONE3_24V: J2.26, J2.27; also elsewhere on the board
ZONE3_C: J2.30; also elsewhere on the board
ZONE3_N: J2.29; also elsewhere on the board
ZONE3_W: J2.28; also elsewhere on the board
ZONE4_24V: J2.1, J2.2; also elsewhere on the board
ZONE4_C: J2.5; also elsewhere on the board
ZONE4_N: J2.4; also elsewhere on the board
ZONE4_W: J2.3; also elsewhere on the board
ZONE5_24V: J2.6, J2.7; also elsewhere on the board
ZONE5_C: J2.10; also elsewhere on the board
ZONE5_N: J2.9; also elsewhere on the board
ZONE5_W: J2.8; also elsewhere on the board
ZONE6_24V: J2.11, J2.12; also elsewhere on the board
ZONE6_C: J2.15; also elsewhere on the board
ZONE6_N: J2.14; also elsewhere on the board
ZONE6_W: J2.13; also elsewhere on the board

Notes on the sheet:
SIX ZONES / ONE LOCKING FLEX CONNECTION
J2 mates directly to upper LED flex J100. 30 contacts carry 24 independent electrical nets. Fused positive rails remain separate for every zone.
PIN BLOCKS: 4 / 5 / 6 / 1 / 2 / 3 Within each block: +24 V, +24 V, W, N, C Duplicate positive contacts connect ONLY within that zone. No common ground contact; these are switched LED returns.
MATING: Molex 2005280300, bottom contact / Front Flip. Upper-flex contacts are B.Cu; reinforcement is FRONT. Native flex front view, tip up: pin 1 LEFT. Looking directly at gold, tip up: pin 1 RIGHT. Gold faces main PCB when inserted. Mate only with power disconnected; provide strain relief.
Finished insertion thickness 0.30 +/-0.05 mm, all layers included. Fingers: gold >=0.1 um over nickel 1-5 um; no solder coating. Tail dimensional and stack acceptance required from fabricator. See MATING-TAIL-CONTRACT.json and fabrication drawing.



Board: 8 copper layers, 76.2 x 75.1 mm, 262 parts (139 on the bottom side), 163 nets.

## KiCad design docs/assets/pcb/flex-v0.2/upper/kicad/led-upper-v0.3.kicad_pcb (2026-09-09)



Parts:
J11: Z1 S1 TOP; J11_Solder4
J12: Z1 S2 TOP; J12_Solder4
J13: Z1 S3 TOP; J13_Solder4
J14: Z1 S4 TOP; J14_Solder4
J21: Z2 S1 TOP; J21_Solder4
J22: Z2 S2 TOP; J22_Solder4
J23: Z2 S3 TOP; J23_Solder4
J24: Z2 S4 TOP; J24_Solder4
J31: Z3 S1 TOP; J31_Solder4
J32: Z3 S2 TOP; J32_Solder4
J33: Z3 S3 TOP; J33_Solder4
J34: Z3 S4 TOP; J34_Solder4
J41: Z4 S1 TOP; J41_Solder4
J42: Z4 S2 TOP; J42_Solder4
J43: Z4 S3 TOP; J43_Solder4
J44: Z4 S4 TOP; J44_Solder4
J51: Z5 S1 TOP; J51_Solder4
J52: Z5 S2 TOP; J52_Solder4
J53: Z5 S3 TOP; J53_Solder4
J54: Z5 S4 TOP; J54_Solder4
J61: Z6 S1 TOP; J61_Solder4
J62: Z6 S2 TOP; J62_Solder4
J63: Z6 S3 TOP; J63_Solder4
J64: Z6 S4 TOP; J64_Solder4
J100: 30-contact FPC tail / Molex 2005280300; J100_FPC30_BottomContacts

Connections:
Z1_T23_24V: J12.1, J13.1
Z1_T23_C: J12.4, J13.4
Z1_T23_N: J12.3, J13.3
Z1_T23_W: J12.2, J13.2
Z2_T23_24V: J22.1, J23.1
Z2_T23_C: J22.4, J23.4
Z2_T23_N: J22.3, J23.3
Z2_T23_W: J22.2, J23.2
Z3_T23_24V: J32.1, J33.1
Z3_T23_C: J32.4, J33.4
Z3_T23_N: J32.3, J33.3
Z3_T23_W: J32.2, J33.2
Z4_T23_24V: J42.1, J43.1
Z4_T23_C: J42.4, J43.4
Z4_T23_N: J42.3, J43.3
Z4_T23_W: J42.2, J43.2
Z5_T23_24V: J52.1, J53.1
Z5_T23_C: J52.4, J53.4
Z5_T23_N: J52.3, J53.3
Z5_T23_W: J52.2, J53.2
Z6_T23_24V: J62.1, J63.1
Z6_T23_C: J62.4, J63.4
Z6_T23_N: J62.3, J63.3
Z6_T23_W: J62.2, J63.2
ZONE1_24V: J11.1, J100.16, J100.17
ZONE1_C: J11.4, J100.20
ZONE1_N: J11.3, J100.19
ZONE1_W: J11.2, J100.18
ZONE2_24V: J21.1, J100.21, J100.22
ZONE2_C: J21.4, J100.25
ZONE2_N: J21.3, J100.24
ZONE2_W: J21.2, J100.23
ZONE3_24V: J31.1, J100.26, J100.27
ZONE3_C: J31.4, J100.30
ZONE3_N: J31.3, J100.29
ZONE3_W: J31.2, J100.28
ZONE4_24V: J44.1, J100.1, J100.2
ZONE4_C: J44.4, J100.5
ZONE4_N: J44.3, J100.4
ZONE4_W: J44.2, J100.3
ZONE5_24V: J54.1, J100.6, J100.7
ZONE5_C: J54.4, J100.10
ZONE5_N: J54.3, J100.9
ZONE5_W: J54.2, J100.8
ZONE6_24V: J64.1, J100.11, J100.12
ZONE6_C: J64.4, J100.15
ZONE6_N: J64.3, J100.14
ZONE6_W: J64.2, J100.13

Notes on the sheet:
J100 is fabricated gold fingers, not an assembled connector. F-side/stiffener view, tip up: pin 1 LEFT. Gold-face view: pin 1 RIGHT. Six groups: Z4, Z5, Z6, Z1, Z2, Z3; each +,+,W,N,C. Each positive contact alone is rated for the 0.60 A zone screen. No common positive supply across zones. Strip pin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


Board: 2 copper layers, 325.0 x 42.9 mm, 25 parts (0 on the bottom side), 48 nets.

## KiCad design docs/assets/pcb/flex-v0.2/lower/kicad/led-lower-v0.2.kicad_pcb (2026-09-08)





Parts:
J11: Z1 S1 BOTTOM; J11_Solder4
J12: Z1 S2 BOTTOM; J12_Solder4
J13: Z1 S3 BOTTOM; J13_Solder4
J14: Z1 S4 BOTTOM; J14_Solder4
J21: Z2 S1 BOTTOM; J21_Solder4
J22: Z2 S2 BOTTOM; J22_Solder4
J23: Z2 S3 BOTTOM; J23_Solder4
J24: Z2 S4 BOTTOM; J24_Solder4
J31: Z3 S1 BOTTOM; J31_Solder4
J32: Z3 S2 BOTTOM; J32_Solder4
J33: Z3 S3 BOTTOM; J33_Solder4
J34: Z3 S4 BOTTOM; J34_Solder4
J41: Z4 S1 BOTTOM; J41_Solder4
J42: Z4 S2 BOTTOM; J42_Solder4
J43: Z4 S3 BOTTOM; J43_Solder4
J44: Z4 S4 BOTTOM; J44_Solder4
J51: Z5 S1 BOTTOM; J51_Solder4
J52: Z5 S2 BOTTOM; J52_Solder4
J53: Z5 S3 BOTTOM; J53_Solder4
J54: Z5 S4 BOTTOM; J54_Solder4
J61: Z6 S1 BOTTOM; J61_Solder4
J62: Z6 S2 BOTTOM; J62_Solder4
J63: Z6 S3 BOTTOM; J63_Solder4
J64: Z6 S4 BOTTOM; J64_Solder4

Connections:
Z1_B12_24V: J11.1, J12.1
Z1_B12_C: J11.4, J12.4
Z1_B12_N: J11.3, J12.3
Z1_B12_W: J11.2, J12.2
Z1_B34_24V: J13.1, J14.1
Z1_B34_C: J13.4, J14.4
Z1_B34_N: J13.3, J14.3
Z1_B34_W: J13.2, J14.2
Z2_B12_24V: J21.1, J22.1
Z2_B12_C: J21.4, J22.4
Z2_B12_N: J21.3, J22.3
Z2_B12_W: J21.2, J22.2
Z2_B34_24V: J23.1, J24.1
Z2_B34_C: J23.4, J24.4
Z2_B34_N: J23.3, J24.3
Z2_B34_W: J23.2, J24.2
Z3_B12_24V: J31.1, J32.1
Z3_B12_C: J31.4, J32.4
Z3_B12_N: J31.3, J32.3
Z3_B12_W: J31.2, J32.2
Z3_B34_24V: J33.1, J34.1
Z3_B34_C: J33.4, J34.4
Z3_B34_N: J33.3, J34.3
Z3_B34_W: J33.2, J34.2
Z4_B12_24V: J41.1, J42.1
Z4_B12_C: J41.4, J42.4
Z4_B12_N: J41.3, J42.3
Z4_B12_W: J41.2, J42.2
Z4_B34_24V: J43.1, J44.1
Z4_B34_C: J43.4, J44.4
Z4_B34_N: J43.3, J44.3
Z4_B34_W: J43.2, J44.2
Z5_B12_24V: J51.1, J52.1
Z5_B12_C: J51.4, J52.4
Z5_B12_N: J51.3, J52.3
Z5_B12_W: J51.2, J52.2
Z5_B34_24V: J53.1, J54.1
Z5_B34_C: J53.4, J54.4
Z5_B34_N: J53.3, J54.3
Z5_B34_W: J53.2, J54.2
Z6_B12_24V: J61.1, J62.1
Z6_B12_C: J61.4, J62.4
Z6_B12_N: J61.3, J62.3
Z6_B12_W: J61.2, J62.2
Z6_B34_24V: J63.1, J64.1
Z6_B34_C: J63.4, J64.4
Z6_B34_N: J63.3, J64.3
Z6_B34_W: J63.2, J64.2

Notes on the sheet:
Passive copper only. Pin 1=+24V, 2=W, 3=N, 4=C in the OUTSIDE installed view. Separate net names denote isolation ON THIS FLEX, joined by LED-strip through rails only after assembly. Upper unused end pads have explicit no-connects: they are isolated probe/solder lands, not missing routes. No zone b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


Board: 2 copper layers, 325.0 x 7.9 mm, 24 parts (0 on the bottom side), 48 nets.

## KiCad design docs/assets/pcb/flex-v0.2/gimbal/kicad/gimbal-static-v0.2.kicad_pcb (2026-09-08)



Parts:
J1: INPUT / KEEP THIS END; TenNet_WireBank
J2: 25.4 mm CUT TERMINATION; TenNet_WireBank
J3: 50.8 mm CUT TERMINATION; TenNet_WireBank
J4: 76.2 mm CUT TERMINATION; TenNet_WireBank
J5: 101.6 mm CUT TERMINATION; TenNet_WireBank
J6: 127 mm CUT TERMINATION; TenNet_WireBank
J7: 152.4 mm CUT TERMINATION; TenNet_WireBank

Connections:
CAN_H: J1.3, J2.3, J3.3, J4.3, J5.3, J6.3, J7.3
CAN_L: J1.4, J2.4, J3.4, J4.4, J5.4, J6.4, J7.4
GND: J1.2, J2.2, J3.2, J4.2, J5.2, J6.2, J7.2
SPOT1_LED_MINUS: J1.6, J2.6, J3.6, J4.6, J5.6, J6.6, J7.6
SPOT1_LED_PLUS: J1.5, J2.5, J3.5, J4.5, J5.5, J6.5, J7.5
SPOT2_LED_MINUS: J1.8, J2.8, J3.8, J4.8, J5.8, J6.8, J7.8
SPOT2_LED_PLUS: J1.7, J2.7, J3.7, J4.7, J5.7, J6.7, J7.7
SPOT3_LED_MINUS: J1.10, J2.10, J3.10, J4.10, J5.10, J6.10, J7.10
SPOT3_LED_PLUS: J1.9, J2.9, J3.9, J4.9, J5.9, J6.9, J7.9
V24_MOTOR2: J1.1, J2.1, J3.1, J4.1, J5.1, J6.1, J7.1

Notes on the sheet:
STATIC ARM INTERCONNECT. Joint motion uses ordinary end wires. Retain J1. Cut only at 25.4 / 50.8 / 76.2 / 101.6 / 127.0 / 152.4 mm marks. Ten separate nets at every row. Motor return and three spotlight returns are not interchangeable. Physical single copper layer: F.Cu only. KiCad B.Cu is an empt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


Board: 2 copper layers, 152.4 x 9.2 mm, 7 parts (0 on the bottom side), 10 nets.

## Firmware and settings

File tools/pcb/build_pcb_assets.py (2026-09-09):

#!/usr/bin/env python3
"""Build the published assets and generated page blocks for Doc 9.

Three modes:

  build --handoff H   read the hash-verified handoff, derive and copy every
                      published asset into docs/assets/pcb/light-v0.1/
  render              regenerate the page's static blocks from the published
                      JSON (no handoff needed)
  check               re-verify hashes, counts and generated blocks against
                      what is committed (no handoff needed -- this is what CI
                      and the data tests run)

The handoff is opened read-only. Nothing under it is ever written, and the
KiCad exporter is never re-run.

Standard library only: the site's requirements are pinned and CI installs
exactly that list.
"""

import argparse
import hashlib
import json
import math
import re
import shutil
import sys
import zipfile
from pathlib import Path

sys.path.insert(0, str(Path(__file__).resolve().parent))
import flex  # noqa: E402
import svgprep  # noqa: E402
import teaching  # noqa: E402

REPO = Path(__file__).resolve().parents[2]
DOCS = REPO / "docs"
ASSETS = DOCS / "assets" / "pcb" / "light-v0.1"
FLEX_ASSETS = DOCS / "assets" / "pcb" / "flex-v0.2"
PAGE = DOCS / "09-understand-the-pcb.md"
FLEX_PAGE = DOCS / "10-the-flex-circuits.md"

PCB_SHA = "cbb8d9fc060c7f2b3e6b27b096a5728e789e816102ddba393c69e91020144abb"
ZIP_SHA = "b8af46039d91d6fba399add139964047aa11f38d9ec4e6b16c14d5016aba0409"
CSV_SHA = "be0bb641b64e468e1b3f81a90f2c7ffc2de5d578d69865ab15ccb2351b7d45a8"
SHORT = "cbb8d9fc"
REVISION = "LIGHT v0.2 — grouped arm connectors and branding"
SCHEMA = "el-pcb/1"
GENERATED = "2026-09-08"

SCOPE = ("As of 8 September 2026, this branded main revision and all three flex circuits have been "
    "submitted to PCBWay for quotation and engineering review. Earlier main revisions were submitted "
    "to JLCPCB. Five main boards are requested, with two fully assembled with 241 fitted parts each "
    "and three supplied bare, plus two of each passive flex circuit. No payment, procurement or "
    "production release has been authorized. Supplier construction and inspection corrections remain open.")

LAYERS = [
    # id, KiCad name, kind, side, z, label, plain-language note
    ("Edge_Cuts", "Edge.Cuts", "edge", None, 0, "Board outline",
     "the shape the board is cut to, including the flat under the antenna"),
    ("In6_Cu", "In6.Cu", "copper", None, 1, "Inner copper 6 (In6.Cu)", "ground reference; inspect inherited interruptions"),
    ("In5_Cu", "In5.Cu", "copper", None, 2, "Inner copper 5 (In5.Cu)", "signals and protected branches"),
    ("In4_Cu", "In4.Cu", "copper", None, 3, "Inner copper 4 (In4.Cu)", "signals"),
    ("In3_Cu", "In3.Cu", "copper", None, 4, "Inner copper 3 (In3.Cu)", "ground reference; inspect inherited interruptions"),
    ("In2_Cu", "In2.Cu", "copper", None, 5, "Inner copper 2 (In2.Cu)", "24 V distribution plus reviewed signal routes"),
    ("In1_Cu", "In1.Cu", "copper", None, 6, "Inner copper 1 (In1.Cu)", "the ground reference under the outer layer"),
    ("B_Cu", "B.Cu", "copper", "B", 7, "Back copper (B.Cu)", "components, signals and local power on the back"),
    ("F_Cu", "F.Cu", "copper", "F", 8, "Front copper (F.Cu)", "components, signals and local power on the front"),
    ("B_Mask", "B.Mask", "mask", "B", 9, "Back mask openings",
     "where the coating is left off so copper stays exposed -- not the coating itself"),
    ("F_Mask", "F.Mask", "mask", "F", 9, "Front mask openings",
     "where the coating is left off so copper stays exposed -- not the coating itself"),
    ("B_Silkscreen", "B.Silkscreen", "silk", "B", 10, "Back silkscreen", "printed ink labels, not connections"),
    ("F_Silkscreen", "F.Silkscreen", "silk", "F", 10, "Front silkscreen", "printed ink labels, not connections"),
    ("B_Fab", "B.Fab", "fab", "B", 11, "Back assembly outlines",
     "component bodies and reference labels for assembly -- not an electrical layer"),
    ("F_Fab", "F.Fab", "fab", "F", 11, "Front assembly outlines",
     "component bodies and reference labels for assembly -- not an electrical layer"),
    ("B_Courtyard", "B.Courtyard", "courtyard", "B", 12, "Back courtyard",
     "the clearance each part reserves around itself -- nothing physical"),
    ("F_Courtyard", "F.Courtyard", "courtyard", "F", 12, "Front courtyard",
     "the clearance each part reserves around itself -- nothing physical"),
]

SHEET_PLAIN = {
    1: ("The hierarchy map. It has no components of its own -- each box is one of the other 19 sheets, "
        "labelled with its file name.", ["Start here to see how the design is divided"]),
    2: ("The controller: the radio module, its reset and boot circuitry, the UART service port and the ARM "
        "input.", ["U1", "S1", "S2", "J17"]),
    3: ("The power sequence: the supervisor and the gate that decides when lighting is allowed.", ["U18", "U19"]),
    4: ("CAN: the transceiver, its protection, the termination option and both motor connectors.",
        ["U4", "R22", "J12", "J13"]),
    5: ("The USB-C island: connector, protection, presence sensing and the data multiplexer.",
        ["J14", "U17", "U15", "Q30"]),
    6: ("The two PWM expanders and the I2C bus that reaches them.", ["U2", "U3", "R7", "R8"]),
    7: ("Ambient zone 1: three channels, each a gate network and a low-side switch.", ["Q101", "R101", "J2"]),
    8: ("Ambient zone 2, identical in shape to zone 1.", ["Q104", "J3"]),
    9: ("Ambient zone 3, identical in shape to zone 1.", ["Q107", "J4"]),
    10: ("Ambient zone 4, identical in shape to zone 1.", ["Q110", "J5"]),
    11: ("Ambient zone 5, identical in shape to zone 1.", ["Q113", "J6"]),
    12: ("Ambient zone 6, identical in shape to zone 1.", ["Q116", "J7"]),
    13: ("Ambient zone 7 -- the bottom ring. Its connector mates downward from the back face.", ["Q119", "J8"]),
    14: ("The test points: every pad bring-up expects to probe.", ["TP1", "TP7"]),
    15: ("Power, part 1: the input protection chain and the branch fuses.", ["U12", "Q500", "F1", "C504"]),
    16: ("Power, part 2: the 24 V input terminal and the two switching converters.", ["J1", "U10", "U11"]),
    17: ("Spotlight, part 1: the gated supply and the three constant-current driver cells.",
         ["U14", "U7", "U8", "U9"]),
    18: ("Spotlight, part 2: the driver outputs and their connectors.", ["J9"]),
    19: ("Monitoring and expansion: the temperature sensor, the expansion pads, the boot-strap probes and the "
         "mounting holes.", ["U20", "J18", "H1"]),
}

SHEET_PLAIN[20] = ("One locking 30-contact interface for the six radial zones; paired positive contacts keep each fused zone separate.", ["J2", "F4", "F9"])
for _n in range(7, 13):
    SHEET_PLAIN[_n] = ("Ambient zone %d low-side W/N/C switches; outputs now reach the shared J2 interface on sheet 20." % (_n-6), ["Q1%02d" % (1+3*(_n-7)), "J2"])

VALIDATION_PASSED = [
    ("Current branding delta", "Zero current DRC/unconnected items; all non-back-silkscreen native objects identical to electrical baseline 80195efd", "cbb8d9fc branding verification"),
    ("Board / schematic / BOM parity", "262 features; 241 fitted components; 71 BOM rows; 786 logical pins, 757 assigned and 29 no-connects; 879 physical pad objects", "80195efd baseline parity plus current read-only exporter identity checks"),
    ("Electrical rules and physical connectivity", "Baseline ERC and physical-pad connectivity passed, including rejected seeded missing copper; preserved exactly by the branding delta", "80195efd FINAL-NATIVE-CHECKS; not a new analogue simulation"),
    ("Manufacturing export comparison", "Current 14 non-back-silkscreen films and both drill files match baseline; baseline independent CAM compared 12 films and 868 drills", "Fresh cbb8d9fc exports and 80195efd CAM checks"),
    ("Arm connector change", "J9 combines three independent LED pairs; J10/J11 removed. J13 tilt and J12 pan remain separate. No returns are joined", "Current native schematic, six J9 contacts and matched placement data"),
    ("Central LED interface preserved", "J2 and the upper tail are unchanged from the reviewed 30-contact interface", "Native preservation; physical mating is unmeasured"),
]


VALIDATION_NOT_DONE = [
    "No board has been powered. There is no measurement of any kind on this revision.",
    "No firmware has been built or flashed. The channel map is an integration contract, not code.",
    "The factory stack-up, finished thickness, copper weight and plating are not accepted yet.",
    "The 90 Ohm USB differential geometry is a request to the factory. Historical modelled cases on earlier native "
    "geometry are not a current-board impedance guarantee.",
    "No USB certification, enumeration test or electrostatic-discharge test.",
    "The coupled startup of the two switching converters was never qualified; the vendor model would not run.",
    "Real falling-edge timing, reset recovery and inhibit behaviour are hardware observations not yet made.",
    "No EMC, radio or in-enclosure antenna measurement.",
    "Motor regeneration has no qualified path. Nothing on this board is a brake.",
    "No enclosed-temperature measurement or full-board thermal simulation on this revision. Historical copper-solver totals are not current results.",
    "Actual strip and motor currents are unmeasured; the load model is conditional arithmetic.",
    "C504 final factory installation and the no-wash J2 assembly sequence need supplier approval.",
]

FORBIDDEN_EVERYWHERE = [
    (r"[A-Za-z]:[\\/]Users[\\/]", "a Windows user path"),
    (r"/Users/", "a home directory path"),
    (r"Marcelo", "the author's name"),
    (r"(?:W\d{7,}[A-Z0-9]*|T-\d+C\d+W\d+[A-Z]*)", "a vendor inquiry id"),
    (r"ParentId", "a vendor message id"),
    (r"website_quote_quantity", "quote quantities"),
    (r"purchased_quantity", "quote quantities"),
]
FORBIDDEN_IN_ASSETS = [
    (r"assembles locally", "superseded assembly wording"),
    (r"iron-only", "superseded assembly wording"),
]

MARK = "<!-- el-pcb:generated %s %s -->"


# --------------------------------------------------------------------------- helpers
def sha256(path):
    h = hashlib.sha256()
    with open(path, "rb") as fh:
        for chunk in iter(lambda: fh.read(1 << 20), b""):
            h.update(chunk)
    return h.hexdigest()


def sha256_bytes(data):
    return hashlib.sha256(data).hexdigest()


def write_bytes(path, data):
    path.parent.mkdir(parents=True, exist_ok=True)
    with open(path, "wb") as fh:
        fh.write(data)


def write_json(path, obj):
    text = json.dumps(obj, ensure_ascii=False, separators=(",", ":"))
    write_bytes(path, text.encode("utf-8"))


def write_text(path, text):
    write_bytes(path, text.encode("utf-8"))


def read_json(path):
    with open(path, "rb") as fh:
        return json.loads(fh.read().decode("utf-8"))


def header(extra=None):
    h = {"schema": SCHEMA, "pcb_sha256": PCB_SHA, "revision": REVISION, "generated": GENERATED}
    if extra:
        h.update(extra)
    return h


def esc(text):
    return (str(text).replace("&", "&amp;").replace("<", "&lt;").replace(">", "&gt;")
            .replace('"', "&quot;"))


def human_bytes(n):
    if n >= 1024 * 1024:
        return "%.1f MB" % (n / 1048576.0)
    if n >= 1024:
        return "%.0f kB" % (n / 1024.0)
    return "%d bytes" % n


def ref_key(ref):
    m = re.match(r"^([A-Za-z]+)(\d+)$", ref)
    return (m.group(1), int(m.group(2))) if m else (ref, 0)


# Pad outlines are drawn as translate(cx cy) rotate(-rot) around the pad centre.
# A pad's axis-aligned box is the rotated *inner* rectangle grown by the corner
# radius, which is why a rotated rounded pad is smaller than a sharp one.
def pad_extent(pad):
    w, h = pad["size"]
    t = math.radians(pad["rot"])
    shape = pad["shape"]
    if shape == 0:
        return w, h
    if shape == 2:
        r = min(w, h) / 2.0
    elif shape in (4, 5):
        r = pad.get("r") or 0.0
    else:
        r = 0.0
    iw, ih = max(w - 2 * r, 0.0), max(h - 2 * r, 0.0)
    return (abs(iw * math.cos(t)) + abs(ih * math.sin(t)) + 2 * r,
            abs(iw * math.sin(t)) + abs(ih * math.cos(t)) + 2 * r)


def check_pad_geometry(components):
    """Every pad's drawn outline must reproduce the exported bounding box, and
    the rotation sign must be the one that puts J12/J13's pad rows square to
    their pad axes. Custom-shaped pads are drawn from their box and excluded."""
    custom = []
    for c in components:
        for pad in c["pads"]:
            if pad["shape"] == 6:
                custom.append("%s.%s" % (c["ref"], pad["n"]))
                continue
            ew, eh = pad_extent(pad)
            if abs(ew - pad["bbox"][2]) > 1e-3 or abs(eh - pad["bbox"][3]) > 1e-3:
                sys.exit("pad %s.%s does not reproduce its exported box" % (c["ref"], pad["n"]))
    by_ref = {c["ref"]: c for c in components}
    for ref in ("J12", "J13"):
        pads = {p["n"]: p for p in by_ref[ref]["pads"]}
        p1, p3 = pads["1"]["xy"], pads["3"]["xy"]
        row = (p3[0] - p1[0], p3[1] - p1[1])
        length = math.hypot(*row)
        row = (row[0] / length, row[1] / length)
        t = math.radians(-by_ref[ref]["rot"])
        axis = (-math.sin(t), math.cos(t))
        if abs(axis[0] * row[0] + axis[1] * row[1]) > 0.02:
            sys.exit("%s: rotate(-rot) does not put the pad row square to the pad axis -- "
                     "the rotation sign is wrong" % ref)
    return sorted(custom)


# --------------------------------------------------------------------------- build
def verify_snapshot(folder):
    """Check every deliberately cut source byte before deriving any public file."""
    root = Path(folder).resolve()
    manifest = read_json(root / "MANIFEST.json")
    for entry in manifest["files"]:
        path = (root / entry["path"]).resolve()
        if not path.is_relative_to(root) or not path.is_file():
            sys.exit("invalid snapshot member: " + entry["path"])
        if sha256(path) != entry["sha256"] or path.stat().st_size != entry["bytes"]:
            sys.exit("snapshot hash/size mismatch: " + entry["path"])
    print("snapshot manifest verified: %d files" % len(manifest["files"]))


def build(handoff):
    verify_snapshot(handoff)
    H = Path(handoff)
    if not H.is_dir():
        sys.exit("handoff folder not found: %s" % H)

    src_pcb = H / "hardware-current/hardware/rev-a/engineered-lighting-rev-a.kicad_pcb"
    src_zip = H / "downloads/LIGHT-v0.2-cbb8d9fc-KiCad-project.zip"
    src_csv = H / "hardware-current/manufacturing/quote_bom.csv"
    for path, want, what in ((src_pcb, PCB_SHA, "governing PCB"),
                             (src_zip, ZIP_SHA, "KiCad project ZIP"),
                             (src_csv, CSV_SHA, "BOM CSV")):
        got = sha256(path)
        if got != want:
            sys.exit("%s hash mismatch\n  expected %s\n  got      %s" % (what, want, got))
    print("hash chain verified: PCB, project ZIP and BOM CSV all match the governing revision")

    board_src = read_json(H / "viewer-data/board.json")
    bom_src = read_json(H / "viewer-data/bom.json")
    sch_src = read_json(H / "schematic-view/index.json")
    zip_src = read_json(H / "downloads/index.json")
    for name, obj in (("board.json", board_src), ("bom.json", bom_src), ("schematic index", sch_src)):
        if obj.get("pcb_sha256") != PCB_SHA:
            sys.exit("%s does not carry the governing hash" % name)

    if ASSETS.exists():
        shutil.rmtree(ASSETS)
    ASSETS.mkdir(parents=True)

    provenance = {"sources": {}, "layers": {}, "schematic": {}, "census": {}, "notes": []}
    provenance["sources"] = {
        "engineered-lighting-rev-a.kicad_pcb": {"sha256": PCB_SHA, "bytes": src_pcb.stat().st_size},
        "LIGHT-v0.2-cbb8d9fc-KiCad-project.zip": {"sha256": ZIP_SHA, "bytes": src_zip.stat().st_size},
        "quote_bom.csv": {"sha256": CSV_SHA, "bytes": src_csv.stat().st_size,
                          "encoding": "UTF-8 with byte-order mark"},
        "handoff_folder": H.name,
    }

    # ---- layers -----------------------------------------------------------
    by_side = {"F": set(), "B": set()}
    for c in board_src["components"]:
        by_side[c["side"]].add(c["ref"])

    layer_meta = []
    for lid, kicad, kind, side, z, label, plain in LAYERS:
        src = H / "viewer-data/layers" / ("%s.svg" % lid)
        text = src.read_text(encoding="utf-8")
        refs = by_side[side] if kind == "fab" and side else set()
        out, stats = svgprep.prepare(
            text, refs=refs, recolour=True, normalise_mask=(kind == "mask"),
            extra_attrs={"data-layer": lid})
        counts = svgprep.verify(text, out)
        dest = ASSETS / "layers" / ("%s.svg" % lid)
        write_text(dest, out)
        layer_meta.append({
            "id": lid, "kicad": kicad, "kind": kind, "side": side, "z": z,
            "file": "layers/%s.svg" % lid, "label": label, "plain": plain,
            "bytes": dest.stat().st_size, "sha256": sha256(dest),
        })
        provenance["layers"][lid] = {
            "source_sha256": sha256(src), "source_bytes": src.stat().st_size,
            "published_sha256": sha256(dest), "published_bytes": dest.stat().st_size,
            "paths": counts["paths"], "circles": counts["circles"],
            "groups_before": counts["groups_before"], "groups_after": counts["groups_after"],
            "text_removed": counts["text_before"], "text_after": stats["text_after"],
            "hex_colors_after": stats["hex_colors_after"],
            "data_ref_tags": stats["data_ref_tags"], "data_ref_unique": stats["data_ref_unique"],
        }
        if kind == "fab" and side:
            missing = by_side[side] - set(stats["tagged_refs"])
            if missing:
                sys.exit("%s is missing reference labels for %s" % (lid, sorted(missing)[:8]))
    print("17 layer plots prepared (colours neutralised, invisible text removed, Fab labels tagged)")

    # ---- silhouette -------------------------------------------------------
    edge = (H / "viewer-data/layers/Edge_Cuts.svg").read_text(encoding="utf-8")
    arc = re.search(r'd="(M([\d.]+) ([\d.]+) A([\d.]+) ([\d.]+) ([\d.]+) (\d) (\d) ([\d.]+) ([\d.]+))"', edge)
    if not arc:
        sys.exit("could not find the outline arc in Edge_Cuts.svg")
    sx, sy, rx, ry, rot, large, sweep, ex, ey = (float(arc.group(i)) if i not in (7, 8) else int(arc.group(i))
                                                 for i in range(2, 11))
    silhouette = "%s Z" % arc.group(1)
    cx, cy = board_src["center_mm"]
    r = board_src["nominal_radius_mm"]
    chord = float(board_src["antenna_chord_y_mm"])
    computed = [cx - r, chord, 2 * r, cy + r - chord]
    outline = board_src["outline_bounds_mm"]
    if max(abs(a - b) for a, b in zip(computed, outline)) > 1e-6:
        sys.exit("silhouette bbox %s does not match the outline %s" % (computed, outline))
    if abs(sx - (cx - (r ** 2 - (cy - chord) ** 2) ** 0.5)) > 1e-3 or abs(sy - chord) > 1e-6:
        sys.exit("outline arc does not start on the antenna chord")

    # ---- components -------------------------------------------------------
    ref_to_sheet = {k: int(v) for k, v in sch_src["component_to_sheet"].items()}
    sheet_title = {s["number"]: s["title"] for s in sch_src["sheets"]}
    bom_rows_src = bom_src["rows"]
    row_by_item = {r["Item"]: r for r in bom_rows_src}
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

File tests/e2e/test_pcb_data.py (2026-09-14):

"""Data and asset checks for Doc 9's published PCB material.

These run without a browser. They guard the things `mkdocs build --strict`
cannot see: the hash chain from the governing board file through to every
published byte, the counts the page states as fact, the joins between the
board, the parts list, the teaching content and the schematic, and the raw
HTML links the Markdown validator ignores.

They live in tests/e2e so the repo's single test command picks them up.
"""

import json
import math
import pathlib
import re
import subprocess
import sys
import zipfile

import pytest

REPO = pathlib.Path(__file__).resolve().parents[2]
ASSETS = REPO / "docs" / "assets" / "pcb" / "light-v0.1"
PAGE = REPO / "docs" / "09-understand-the-pcb.md"
SITE = REPO / "site"

PCB_SHA = "cbb8d9fc060c7f2b3e6b27b096a5728e789e816102ddba393c69e91020144abb"
ZIP_SHA = "b8af46039d91d6fba399add139964047aa11f38d9ec4e6b16c14d5016aba0409"
CSV_SHA = "be0bb641b64e468e1b3f81a90f2c7ffc2de5d578d69865ab15ccb2351b7d45a8"

LANDMARKS = {
    "J1": ("F", [84.5, 126.5], -90.0, 16),
    "U1": ("F", [100.0, 72.6], 0.0, 2),
    "J14": ("F", [100.0, 134.425], 0.0, 5),
    "C504": ("B", [100.0, 114.0], 0.0, 15),
    "J12": ("B", [88.5, 130.0], 160.0, 4),
    "J13": ("B", [113.0, 129.5], -160.0, 4),
    "H1": ("F", [83.0, 70.5], 0.0, 19),
    "H2": ("F", [117.0, 70.5], 0.0, 19),
    "H3": ("F", [76.0, 124.0], 0.0, 19),
    "H4": ("F", [124.0, 124.0], 0.0, 19),
    "C512": ("B", [None, None], None, 16),
}

TP_NETS = {
    "TP1": "GND", "TP2": "VIN24_RAW", "TP3": "V24_BUS", "TP4": "+5V", "TP5": "+3V3",
    "TP6": "GATE_BIAS", "TP7": "LIGHT_ENABLE_SAFE", "TP8": "EFUSE_RESET_N",
    "TP9": "V24_SPOT", "TP10": "I2C_SDA", "TP11": "I2C_SCL", "TP12": "PCA_OE",
}


def load(name):
    with open(ASSETS / name, "rb") as fh:
        return json.loads(fh.read().decode("utf-8"))


def sha256(path):
    import hashlib
    h = hashlib.sha256()
    with open(path, "rb") as fh:
        for chunk in iter(lambda: fh.read(1 << 20), b""):
            h.update(chunk)
    return h.hexdigest()


@pytest.fixture(scope="module")
def board():
    return load("board.json")


@pytest.fixture(scope="module")
def bom():
    return load("bom.json")


@pytest.fixture(scope="module")
def teach():
    return load("teaching.json")


@pytest.fixture(scope="module")
def sch():
    return load("schematic/index.json")


def test_generator_check_passes():
    """The build tool's own drift check, which CI can run without the handoff."""
    result = subprocess.run(
        [sys.executable, str(REPO / "tools" / "pcb" / "build_pcb_assets.py"), "check"],
        capture_output=True, text=True, cwd=str(REPO))
    assert result.returncode == 0, result.stdout + result.stderr


def test_hash_chain(bom):
    assert sha256(ASSETS / "kicad/engineered-lighting-rev-a.kicad_pcb") == PCB_SHA, (
        "the published board file no longer hashes to the governing revision - if this fails after a "
        "fresh clone, docs/assets/pcb/.gitattributes is missing or wrong")
    zpath = ASSETS / "downloads/LIGHT-v0.2-cbb8d9fc-KiCad-project.zip"
    assert sha256(zpath) == ZIP_SHA
    csv = ASSETS / bom["csv_file"]
    assert sha256(csv) == CSV_SHA
    assert csv.read_bytes()[:3] == b"\xef\xbb\xbf", "the parts CSV lost its byte-order mark"
    for name in ("board.json", "bom.json", "teaching.json", "provenance.json",
                 "schematic/index.json", "downloads/manifest.json"):
        assert load(name)["pcb_sha256"] == PCB_SHA, name
    assert not list(ASSETS.rglob("*.kicad_prl")), "personal editor state must never be published"


def test_project_zip_contents():
    zpath = ASSETS / "downloads/LIGHT-v0.2-cbb8d9fc-KiCad-project.zip"
    with zipfile.ZipFile(zpath) as zf:
        names = zf.namelist()
    assert len(names) == 63, names
    assert sum(1 for n in names if n.endswith(".kicad_sch")) == 20
    assert sum(1 for n in names if n.endswith(".kicad_sym")) == 15
    for required in ("engineered-lighting-rev-a.kicad_pro", "engineered-lighting-rev-a.kicad_pcb",
                     "engineered-lighting-rev-a.kicad_dru", "fp-lib-table", "sym-lib-table",
                     "SOURCE-MANIFEST.json"):
        assert required in names, required
    assert any(n.startswith("EL.pretty/") for n in names)
    assert any(n.startswith("ELF.pretty/") for n in names)
    assert not any(n.endswith(".kicad_prl") for n in names)


def test_manifest_and_layers_resolve(board, sch):
    manifest = load("downloads/manifest.json")
    for item in manifest["items"]:
        path = ASSETS / item["file"]
        assert path.exists(), item["file"]
        assert path.stat().st_size == item["bytes"], item["file"]
        assert sha256(path) == item["sha256"], item["file"]
    assert len(board["layers"]) == 17
    for layer in board["layers"]:
        path = ASSETS / layer["file"]
        assert path.exists() and sha256(path) == layer["sha256"], layer["id"]
    assert len(sch["sheets"]) == 20
    for sheet in sch["sheets"]:
        path = ASSETS / sheet["file"]
        assert path.exists() and sha256(path) == sheet["sha256"], sheet["n"]


def test_board_census(board):
    comps = {c["ref"]: c for c in board["components"]}
    assert len(comps) == 262
    assert board["sides"] == {"F": 123, "B": 139}
    assert sum(1 for c in comps.values() if c["side"] == "F") == 123
    assert len(board["features"]) == 21
    assert sum(1 for c in comps.values() if not c["feature"]) == 241
    assert len(board["nets"]) == 163
    assert not [n for n in board["nets"] if n.startswith("unconnected-")]
    nc = sum(1 for c in comps.values() for v in c["pins"].values() if v is None)
    assert nc == 29
    pads = [p for c in comps.values() for p in c["pads"]]
    assert len(pads) == 879
    assert sum(1 for p in pads if p.get("paste")) == 18

    assert sorted(r for r, c in comps.items() if c["through"]) == ["H1", "H2", "H3", "H4", "J14"]
    thermal = {r: c["thermal_vias"] for r, c in comps.items() if c["thermal_vias"]}
    assert thermal == {"U10": 8, "U11": 2, "U12": 9, "U14": 6, "U500": 2, "U501": 2}

    outline = board["frame"]["outline"]
    overhang = sorted(r for r, c in comps.items()
                      if c["bbox"][0] < outline[0] or c["bbox"][1] < outline[1]
                      or c["bbox"][0] + c["bbox"][2] > outline[0] + outline[2]
                      or c["bbox"][1] + c["bbox"][3] > outline[1] + outline[3])
    assert overhang == ["J14", "J17", "U1"]
    assert board["frame"]["fit"] == [61.225, 56.49, 77.55, 82.14]

    for ref, (side, xy, rot, sheet) in LANDMARKS.items():
        c = comps[ref]
        assert c["side"] == side, ref
        assert c["sheet"] == sheet, (ref, c["sheet"])
        if xy[0] is not None:
            assert c["xy"] == xy, ref
            assert c["rot"] == rot, ref
    for ref in ("H1", "H2", "H3", "H4"):
        pad = comps[ref]["pads"][0]
        assert pad["attr"] == 3 and pad["drill"] == [3.2, 3.2], ref
    assert all(c["pkg"] for c in comps.values())
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

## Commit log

2026-07-20 Scaffold: allowlist .gitignore + pinned site toolchain
    Allowlist-style ignore keeps the co-located unrelated project (src/,
    scripts/, pyproject.toml, .env, feeds.json) permanently untracked.
    Pins from a local Python 3.9 venv resolve to mkdocs-material 9.7.7 /
    mkdocs 1.6.1 — same versions CI will install on Python 3.12.
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2026-07-20 Interactive BoM checklist: 30 items, localStorage persistence
    Three collapsible sections mirroring the Doc 3/4/5 BoM tables.
    Plain HTML checkboxes + ~100 lines of vanilla JS (el-bom-v1 store,
    per-section progress with midpoint dollar sums, global bar, reset,
    copy-unchecked-as-shopping-list with clipboard fallback).
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2026-07-20 Fix list rendering: blank lines before 5 lists + sane_lists + nest indent
    Python-Markdown (unlike GitHub's preview) requires a blank line before
    a list, so five list blocks rendered as run-on paragraph text — incl.
    Doc 4's Stage 7 verdict checklist as literal '- [ ]'. Whitespace-only
    repairs: blank line at each site, 4-space nesting for doc 6's detector
    sub-list, and sane_lists so doc 4's steps keep their 4/5 numbering.
    Found by the post-deploy adversarial review.
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2026-07-20 Landing hero
    Replaces the plain title block with the design's cone-of-light hero:
    kicker, headline, split vision paragraph, meta chips. All other
    landing content unchanged.
2026-07-20 QA fixes: rendering, theme coverage, checklist robustness
    From the adversarial QA pass (7 confirmed, 2 plausible findings):
    doc 4's prerequisites list renders as a proper ol (blank quote line);
    chapter task-list checkboxes get the theme's check language (ink-3
    unchecked, amber checked) instead of invisible boxes and Material
    green; the content mark override is scoped to .md-content so search
    hits keep their accent; the hero cone loses its side bleed on phones
    (horizontal-scroll guard); copy buttons no longer stick at Copied
    after a double-click and report failure honestly; localStorage state
    is shape-validated on load.
2026-07-20 Feedback round: captions, descriptions, aria labels, cross-links
    Strips the source-bundle folder advice from two diagram captions;
    adds quoted per-page meta descriptions (unquoted colons were silently
    dropping whole front-matter blocks, taking the short nav titles with
    them); adds aria-labels with part names to all 30 BoM checkboxes and
    labels the global progress bar; converts ~56 plain-text Doc-N
    cross-references into links sitewide (code spans, headings, and doc
    1's map table excluded; self-references left plain).
2026-07-20 CI: acceptance tests gate the deploy
    Playwright (Python) e2e suite: checklist persistence across reload,
    section-scoped reset, copy-list shape, progress math, and 390/1280
    screenshots uploaded as run artifacts. The workflow gains a test job
    the deploy depends on, plus the add-a-doc nav check. Unreferenced
    wiring PNGs stay in the repo but leave the built site (exclude_docs).
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2026-07-21 Round-2 structure: notebook posture, linked maps, deep links
    Home gains the internal-notebook posture line, a July 2026 dateline
    chip, and the fully linked reading-paths line; Doc 1's map now matches
    Home's linked version (no internal filenames). Doc 3 gains the risk
    register and Further reading its siblings have. Doc 5 BoM rows carry
    phase tags, phases 2-5 are marked greenfield, the FCC note no longer
    silently rots, and the stereo row shows its real prices. Section
    references deep-link to their anchors (Doc 6 §1, Doc 5 Phases 0/1,
    Doc 4's prerequisites box); Further-reading citations are hyperlinks;
    Doc 6 drops an internal editorial aside.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
2026-07-21 Motor swap: RMD-L-4005 → RMD-L-5005 in everything forward-looking
    The 4005 sold out at retail; the in-stock sibling 5005 ($107.50,
    Dings Motion USA) is the build's motor — same protocol, wiring, and
    command set. Doc 3's BoM, prompts, diagrams, and totals move to the
    5005 with a third-unit spare recommended; Doc 2 keeps its historical
    decision record and gains an availability addendum with the sibling
    table and pick logic. Doc 3 total ~$185–290 → ~$340–385; end-to-end
    $475–850 → $630–945, propagated to every occurrence. Alternates line
    (GL40 II, RollerCAN) added as supply insurance; risk register gains
    supply volatility. Checklist id d3-motors unchanged — saved state
    survive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
2026-07-29 Add PROJECT-STATE handoff + pending Claude Code prompts (motor swap, frame chapter)
2026-07-29 PROJECT-STATE: reconcile with repo history + bank the fixture-integration plan
    The 2026-07-28 handoff listed the motor-swap and frame-chapter prompts as
    pending, but 8fb39bf (07-21) and db41f3f (07-22) had already executed them.
    Snapshot and queue now reflect reality: next action is the Dings order.
    Also banks the post-bench fixture-v0 plan: hand-soldered stack on 72mm
    round protoboards, E26-fed IRM-90-24ST, board allocation B1 power /
    B2 drivers / B3 logic, XT30 motor power, and the full set of review
    deltas (fuse sizing at 2x tape, 1000uF bulk-cap start, six-conductor
    spot wiring, bench-limit 3A for full-stack tests).
    Claude-Session: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
2026-07-29 Doc 8 assets: fixture-v0 wiring map + six step diagrams
    The lane-based system map (three subsystem lanes, power trunks, physical
    side-view panel, six traps) and the per-step wiring diagrams: power
    backbone, brain, zone 1, scale to 7, spotlight, gimbal — each with a
    done-when bar and trap callouts. Board allocation B1 power / B2 drivers /
    B3 logic. SVG-only, matching the exclude rule for PNG fallbacks.
    Claude-Session: https://claude.ai/code/session_01DjSsWY9rGfwYWWb69x42GA
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2026-07-29 Doc 8 assets (3/3): the lane-based wiring map
    The overview diagram: three subsystem lanes read left-to-right from one
    C6 (tape, spotlight, gimbal), two power trunks, a physical side-view
    panel of the whole fixture, board key, and the six traps.
    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
2026-07-29 Doc 8: Build the Fixture — the six-step wiring course
    The hand-soldered fixture build: stacked 72mm protoboards, E26-fed
    IRM-90-24ST, board allocation B1 power / B2 drivers / B3 logic (chosen
    so only ~a dozen wires cross boards). Every step follows one rhythm:
    diagram, what's happening, do-this list, done-when, if-stuck — with the
    traps as callouts, a full in-chapter BoM (net-new vs carried-over), a
    concepts block, five protoboard-soldering rules, per-step time
    estimates, and the step-7 soak agent prompt. Two adversarial review
    rounds applied (electrical + beginner walk-through).
    Claude-Session: https://claude.ai/code/session_01DjSs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
2026-07-29 Doc 8 ripples: doc maps, eight-document wording, totals to $745-1105
    Home and Doc 1 gain row 8 in the document map and a "Making it
    permanent?" reading path; the series wording moves from seven documents
    to eight; the end-to-end hardware total propagates $640-985 -> $745-1105
    in the hero meta, footer, and Doc 1 reading-paths line; the BoM-checklist
    page notes Doc 8's fixture-stage additions live in its chapter BoM for
    now (interactive-checklist integration is a deliberate follow-up).
    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
2026-07-29 BoM checklist: note that Doc 8's additions live in its chapter for now
    Folding the fixture-stage items into the interactive checklist touches
    localStorage IDs and progress totals, so it gets its own careful edit
    later; until then the pointer keeps the site honest.
    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
2026-07-29 Doc 8: align the five soldering rules with the reviewed wording
    The pushed chapter carried an earlier draft's phrasing for the five
    protoboard rules; this restores the tightened, build-verified version
    (incl. the board-gets-the-header / load-gets-the-plug rule).
    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
2026-07-29 Sitewide review: Doc 8 owns its shell gap + Home card covers the fixture
    Review catch 1: Doc 8 told readers to mount the IRM "to the body" but the
    fixture body/shell is deliberately undesigned — the chapter now says so
    plainly (steps 1-6 run on a bench plate; the shell is a Doc 3b-style
    OpenSCAD session once parts are in hand) and step 1 no longer assumes a
    body exists. Review catch 2: Home's "what we're building toward" cards
    orphaned Doc 8 — the spotlight card now carries the build through the
    hand-soldered fixture. PROJECT-STATE: published-page review is done;
    checklist integration remains.
    Claude-Session: https://claude.ai/code/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
2026-07-29 Doc 4: the graduation line now routes through Doc 8
    Review catch: Doc 4's verdict jumped straight from breadboard to "the
    fixture PCB" — a reader finishing stage 7 never learned that Doc 8 is
    the hand-built step in between. One sentence stitches the seam.
    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
2026-07-29 Doc 8: the body is its own design track, with an interface list
    The shell-comes-later scope note becomes a handoff: the body is being
    designed separately, and the chapter now states the seven things that
    design owes the electronics (PSU mount, cord entry, stack standoffs +
    vent, tape-ring height, gimbal clearance, heat path, USB window).
    Step 7 points at that list instead of deferring to a future session.
    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
2026-07-29 Totals become derivable: $745–1085 sitewide
    The $1105 high end was prior-$985 + Doc 8's $120 — consistent, but not
    the sum of anything on the page. The straight sum of per-doc highs
    (405 + 240 + 320 + 120) is $1085; Home's hero + footer and Doc 1's
    reading paths now carry it. PROJECT-STATE records the derivation and
    reframes the fixture body as its own design track, matching Doc 8's
    interface note.
    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
2026-07-29 Doc 3: stage 10's graduation line now routes through Doc 8
    "Pass" pointed straight at the fixture's future PCB — a dead end, since
    the hand-built stop (this gimbal plus Doc 4's bench, soldered into a
    real fixture) comes first. One sentence sends the reader to Doc 8.
    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
2026-07-29 Doc 4: restore two dashes the last push dropped
    Stage 2's plain-text wiring block lost 2 of the ground-star line's 40
    dashes in dfd1c71 (transcription slip, disclosed then). Column
    alignment back to the original bytes.
    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
2026-07-29 BoM checklist: Doc 8 folded in — 43 items across four sections
    The fixture stage's 12 net-new parts get their own section (d8-* ids;
    existing saved state is untouched because state is keyed by id, never
    by position). Progress denominator 31→43 and the e2e count assertions
    move with it; d8-irm joins the persistence test. One cross-doc catch
    from auditing every row: the yoke bearing is 683 or 608 (frame.scad +
    Doc 3b agree), not the 6804 Doc 3's BoM listed — fixed in both places.
    All 9 e2e tests pass locally against the built site.
    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
2026-07-29 Payload becomes the DLH-3UP-EH housing; frame.scad v2 + assembly view
    Marcelo mounts the 3-up star in the Ø0.99" finned aluminum housing —
    heatsink and sliding balance mass in one part, wires out the hollow
    NPT rear. The head shell becomes a pinch-collar cradle (ID = payload
    + 0.6 mm ≈ 25.75 mm, M3 pinch bolt locks the slide) and an M8 bolt
    through the 608 into a new end plate is the head's second support.
    Also fixes v1 scaffold gaps: the yoke arms now join the flange disc
    via a bridge bar, and collar bores are teardropped so arms-up
    printing stays support-free. New: docs/cad/assembly.scad (orbit-able
    exploded/assembled view) and a labeled assembly figure in Doc 3b.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
    [assembly.scad, frame.scad]
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2026-07-29 docs/assets: the Doc 3b gimbal assembly figure (fixes strict build)
    The labeled exploded/assembled SVG that 5db7f05 embeds — compact
    quantized renders, base64 wrapped in short lines for the text-only
    push path. CI on the two prior commits red-lined on the missing
    asset; this makes the reference resolve.
    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
2026-07-29 Remove the corrupted assembly-figure asset
    Nothing references it after 4479914; a clean version returns with the
    v3 flat-plate frame redesign.
    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
2026-07-29 PROJECT-STATE: record the frame.scad v3 redesign in the payload ledger
    The spotlight-payload bullet described v2 (bridged arms, teardrop
    collar bores, pinch-collar head shell) — superseded by b11accb's v3:
    nine flat-printed plates, bolted T-joints, real motor mounts, captive
    M8 end-plate nut, face-bolted cradle_ring, and the dropped-figure note.
    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
2026-07-30 frame.scad v4: ground-up redesign — bolts you can reach, printed axle, split clamp
    Marcelo's review of v3 was right on every count, and two of the points were
    structural rather than cosmetic:
    - "the bolt doesn't really make sense -- that should be 3D printed": the M8
    steel axle is gone. The idle side of the tilt axis is a printed `trunnion`
    stub running in the 608, which lives in a flat-printed `bearing_carrier`
    with deliberately oversize screw holes so it FINDS the axis instead of
    fighting it.
    - "many of the parts there's no way for them to attach": every tab, slot and
    captive square nut is gone. Printed-to-motor joints bolt into the motor's
    own threaded holes (both faces hav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
    [assembly.scad, frame.scad]
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2026-07-30 assembly.scad v5: use, not include-override — so nothing can go missing
    The old file did `include <frame.scad>` and then reassigned `part` to suppress
    frame.scad's own render block. That worked from the CLI and was still the wrong
    way to build it: one variable decided whether you saw the machine or the print
    plate. Now it is
    include <frame_params.scad> the one copy of every dimension
    use <frame.scad> the part modules, with no side effects
    so the file draws the assembly and only the assembly, always.
    Everything is in the scene: six printed parts, both RMD-L-5005s with their real
    bolt patterns and connectors, the 608, the DLH-3UP-EH housing with its flush
    front, the C-c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
    [assembly.scad]
2026-07-30 BoM checklist: make the wire and fuse distinctions explicit
    Three wrong-part questions in a row traced to the same two ambiguities, so
    they're now stated once at the top of the page and spelled out per row.
    New callout: solid vs stranded is not interchangeable and the listing photos
    are identical (breadboard contacts and bus rails want solid; anything that
    flexes wants stranded; "marine" and "silicone" are always stranded). And on
    fuses the letters carry the meaning, not the millimetres — GMC/GMA in 5x20,
    MDL/AGC in 6.3x32, and automotive blade fuses are fast-acting and rarely
    stock a 3 A at all.
    Rows made specific:
    - d4-fuse: "3 A slow-blow" -> "5x20 mm holder + T3.15AL250V", with why 3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
2026-07-30 frame_params v6: a tolerance model, and a tilt axis that balances the head
    Three measured constants (hole shrink, bridged-hole shrink, shaft growth) and
    seven fit functions derived from them. Every fit in the project now comes from
    this block instead of a hardcoded number, which is how v5's fatal one got in:
    the trunnion stub was drawn at 7.85 mm to enter an 8.00 mm bearing and would
    have printed at ~8.0.
    axis_z puts the tilt axis 1.45 mm above the housing's axis, which is where the
    measured centre of mass of the whole head actually sits. Free to do, and it
    deletes the balance-trim bolt and its washer stack.
    Claude-Session: https://cla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
    [frame_params.scad]
2026-07-30 frame v6: every fit derived, a coupon that measures your printer, two clashes fixed
    The fatal one first: the trunnion stub was drawn at 7.85 mm to enter an 8.00 mm
    bearing, and external cylinders print OVER size, so it would have come out at
    about 8.0 and never gone in. Nothing in v5 compensated for print error at all.
    Now every fit comes from free_h / free_hx / tap_h / press_h / slip_s / loc_h /
    slot_fit, and tol_coupon measures the three constants those run on.
    Also fixed, all of it found by looking rather than by assuming:
    · holes drilled sideways get their own fit class — six call sites were using the
    vertical number on a bridged hole
    · the cap's body was exactly as wide as the sl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
    [frame.scad]
2026-07-30 assembly v6: no trim washers, the real cable route, and the motor turned the right way
    The head's cap and housing now sit axis_z below the tilt axis, which is where
    the balance comes from — the washer stack and the keel trim bolt are gone.
    The pan motor is drawn at the rotation it actually has to be installed at: its
    side connector faces the base plate's cable trough. Turned 90 deg the other way
    it sits inside the hard-stop post, which is how the interference got into v5 in
    the first place.
    Cable run redrawn to follow the channel that now exists: the housing's stub, the
    channel in the cradle's motor-side plate, the motor's hollow shaft, then the one
    continuous trough down the arm and und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
    [assembly.scad]
2026-07-30 checklist tests: read the totals off the page instead of hardcoding them
    "0/43 items" and "2/14" were literals in the tests, so adding a single line to
    the BoM failed two tests that had nothing to do with the change. They now count
    the checkboxes and assert the arithmetic, which is the behaviour that matters.
    test_global_progress_math also gained the assertion that was actually missing:
    that the progress bar's hardcoded max still equals the number of checkboxes on
    the page. That is the one number a new BoM row can silently desynchronise.
    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
2026-07-30 BoM: the 608 bearing gets its own line, and a wrong current figure gets fixed
    The only bearing in the machine was hiding inside the 3D-printing row as "683 or
    608 bearings" — an either/or where only one is right, on a line nobody reads as a
    part. It carries the idle end of the tilt axis. It now has its own row with the
    size (8 x 22 x 7), the quantity, and what it actually does. Nothing in the design
    uses a 683; that was left over from an earlier version and is gone.
    Also correcting myself: the d4 wire row claimed a ULN output feeding a tape zone
    "carries amps, not milliamps." It does not. Seven zones share about 3.3 ft of
    4.6 W/ft tape, so a zone is roughly 90 mA and 24 AWG is fine. The r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
2026-07-30 frame v7: drawn against the real motor, and a trunnion that is not a needle
    Follows frame_params v7. M2.5 replaces M4 everywhere the rear mount appears, the
    output ring drops from six holes to four, the base plate's hub is sized by the
    motor's rear face rather than by a bolt circle that was never there, and the
    cradle's local bolt pad is deleted because plate_z now reaches the highest
    reachable bolt on its own.
    The trunnion is stepped: Ø14 through the gap, the arm and most of the carrier,
    stepping to Ø7.7 only for the 9 mm inside the 608. The arm's clearance hole grew
    to suit. Eleven times the bending stiffness where the whole head hangs off it.
    The cap's boss-relief patch is gone, repla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
    [frame.scad]
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2026-07-30 Docs: bring the frame chapter and the BoM up to v8
    03b-print-the-frame.md is rewritten. It described six parts, an output boss,
    M4 rear bolts on D43 and a D30 output circle - none of which exist. It now
    describes four parts against the motor as measured out of the vendor STEP,
    and says which numbers are unverified rather than implying all of them are
    known. The bearing-load rating is called out as unpublished, because the
    whole case for the cantilever rests on it not mattering at 0.0146 N.m.
    Also documents the two things that bite people rather than burying them: the
    2.5 mm tapped depth that fixes every M3 at x 10, and the stale-copies failure
    where OpenSCAD collapses unknown names to undef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
    [frame.scad]
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2026-08-26 Doc 4a: two hubs on one bus, drawn and then photographed
    The chapter said seven zones need a second PCA9685 and then never showed one.
    Every wiring figure on the site draws a single hub — correctly, because zone 1
    only needs one — so at the moment the build reaches 21 channels the pictures
    stop, and the reader is left to infer from "same I2C wires, same 3.3 V" that
    the second board costs no C6 pins at all. That inference is the whole answer,
    and asking a beginner to make it unaided is where this chapter was failing.
    Two schematics and four annotated photographs close it. The schematics carry
    the idea: four wires leaving the C6 and tapped twice, in the same left-to-right
    order at every b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
    [a0-bridge_gen.py, two-hubs_gen.py, uln-map_gen.py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]
2026-08-26 Doc 4b: the spotlight at connector level, and the current the board actually sets
    Stage 5 was one correct paragraph resting on everything a beginner does not
    yet have: what a constant-current driver is, which die is which on an unlit
    star, and why the tape chapter's habits all reverse at this corner of the
    bench. Doc 4b is that other half, in 4a's register — the star and the driver
    demystified, the hookup drawn, S1-S10 checkpoints, and a ladder whose
    swap-test splits logic-side from output-side with one moved wire.
    The reversals get named as laws rather than left as instincts. Polarity is
    proven cold, because a reversed die on a CC output floats toward the rail and
    a bare die is rated for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
    [spot-driver_gen.py]
2026-08-26 Doc 4b: the board was the PicoBuck all along, and it ships gentle
    The twin R300s were real; the conclusion drawn from them was not. The builder
    asked one grounding question - "I ordered the PicoBuck on the BoM though?" -
    and SparkFun's own v1.2 schematic answered it: this is the genuine board,
    AL8860 revision, snap-off ears, branding on the back. Each channel carries a
    fixed 0.3-ohm sense resistor AND a second one behind solder jumper SJn, and a
    zoom on the board shows all three jumpers open. As shipped: ~330 mA per
    channel, exactly what the BoM promised. The ~660 reading came from seeing two
    resistors and calling them parallel without tracing the second one's path
    through the open pads sitt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
    [spot-driver_gen.py, spot-star_gen.py]
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2026-09-07 Doc 9: the LIGHT v0.1 PCB, part by part
    The board Doc 8 hand-soldered has been drawn as one eight-layer PCB. This
    chapter is for understanding it before it exists in your hands.
    The centrepiece is an interactive viewer of the real layout, built from the
    board's own export: 17 native layer plots recoloured to the site's tokens,
    land shapes and holes drawn from the pad data, and 269 hit regions resolved
    by a deterministic chooser so a click in a dense corner lands on the small
    part, not the connector it sits inside. The physical back view is one mirror
    about the board's centre line, verified against J1, U1, J14, C504, J12/J13
    and the four mounting holes.
    Every one of the 269 features is expl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
    [LIGHT-v0.1-c046202e-bom.csv, can.kicad_sch, controller.kicad_sch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]
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2026-09-07 Doc 10: wiring that is manufactured, not cut
    Three passive flexible circuits from their own KiCad sources: an arm ribbon and
    two cylinder bands that replace most of the hand-cut wire between the main board
    and the LED strips. Each is governed by its own .kicad_pcb hash, verified on the
    way in and again from the staged git blobs.
    The hard part was registration. KiCad plots these layers in a CAM frame rather
    than in board millimetres, so the pad coordinates from the connection tables
    would have landed somewhere plausible but wrong on top of them. The builder now
    parses KiCad's own translate/scale wrapper and rewrites each plot into native
    millimetres; a browser test measures the rendered copp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
    [connection-table.csv, gimbal-static-v0.2.kicad_pcb, gimbal-static-v0.2.kicad_sch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]
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2026-09-14 Add audited PCB fixture shopping checklist with saved progress
    [teaching.py, test_pcb_data.py]
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
